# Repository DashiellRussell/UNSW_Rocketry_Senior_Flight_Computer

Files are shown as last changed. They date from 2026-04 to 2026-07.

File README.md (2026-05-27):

# UNSW Rocketry Senior Flight Computer

KiCad project for the senior flight computer used by UNSW Rocketry.

## Revisions

This repo holds each hardware revision in its own self-contained folder. Every
folder is a complete KiCad project (schematic, PCB, and its own copy of the
footprint library) so any revision can be opened and fabricated independently.

| Revision | Folder | Status |
| --- | --- | --- |
| **v0.0** | [`v0.0/`](v0.0/) | Frozen — known-good design. Do not edit. |
| **v1.0** | [`v1.0/`](v1.0/) | In progress — next revision (component + design changes). |

The exact v0.0 snapshot is also recoverable from the `v0.0` git tag
(`git checkout v0.0`).

> **Working on a new revision?** Copy the latest frozen folder to the next
> version number (e.g. `cp -R v1.0 v1.1`), then edit the copy. Tag the old one
> before you move on.

## Documents

Reference docs live in [`docs/`](docs/) and render inline on GitHub:

- [Schematic (PDF)](docs/UNSW_Rocketry_Senior_Flight_Computer.pdf) — exported full schematic (v0.0)
- [Project OZONE](docs/Project%20OZONE.pdf)

## Project layout (within each revision folder)

| File | Purpose |
| --- | --- |
| `UNSW_Rocketry_Senior_Flight_Computer.kicad_pro` | KiCad project file |
| `UNSW_Rocketry_Senior_Flight_Computer.kicad_sch` | Top-level schematic |
| `UNSW_Rocketry_Senior_Flight_Computer.kicad_pcb` | PCB layout |
| `Power.kicad_sch` | Power sheet |
| `Pyros.kicad_sch` | Pyrotechnic channels sheet |
| `Comms.kicad_sch` | Communications sheet |
| `Peripherals.kicad_sch` | Peripherals sheet |
| `Indication.kicad_sch` | Status / indication sheet |
| `UNSW_ROCKETRY_LIBRARY.pretty/` | Project-specific footprint library |
| `UNSW_Rocketry_Senior_Flight_Computer.csv` | BOM export |

## Opening the project

1. Install [KiCad 10.0](https://www.kicad.org/download/) or newer.
2. Clone this repo.
3. Open the `.kicad_pro` inside the revision folder you want, e.g.
   `v1.0/UNSW_Rocketry_Senior_Flight_Computer.kicad_pro`.

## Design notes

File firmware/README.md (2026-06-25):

# OZONE flight computer — firmware

Firmware for the Project OZONE senior flight computer (STM32L452RET6).

## Layout
```
firmware/
├── SETUP.md          CubeMX project setup (do this first)
└── ozone-fw/         CubeMX-generated project (toolchain: STM32CubeIDE)
    ├── ozone-fw.ioc
    ├── Core/ Drivers/ FATFS/ USB_DEVICE/   (CubeMX-managed)
    └── app/          portable application code (survives .ioc regen)
        ├── INTEGRATION.md  how to wire app/ into main.c
        ├── Inc/      headers
        └── Src/      sources
```

## Quick start
1. Generate the CubeMX project per **SETUP.md**.
2. Integrate the **app/** layer per **app/INTEGRATION.md**.
3. Build, flash via SWD (J4), watch the heartbeat LED.

## Modules (`app/`)
| Module | Responsibility |
|---|---|
| `spi_bus` | Shared SPI1 + CS helpers |
| `ms5611` | Barometer (x2), non-blocking conversion SM + compensation |
| `h3lis331dl`  | High-g accel — launch/landing |
| `lis3dh` | Low-g accel — apogee voter |
| `sensors` | Suite bring-up, fusion, ground-zero, altitude |
| `adc_sense` | Battery + pyro-battery voltage (ADC1) |
| `pyro` | Arm / fire / continuity, opto + N-FET |
| `indication`  | RGB (TIM1 PWM), heartbeat/error LEDs, buzzer (TIM17) |
| `logging` | CSV → MicroSD via FatFs/SDMMC |
| `telemetry` | Status over USART2 (BT module) |
| `flight` | State machine + 2-of-3 apogee voting (testable, no HW) |
| `ozone_app` | Top-level init + super-loop |

## Bring-up order (recommended)
1. Power rails (no MCU) — doc §14.1.
2. Flash + heartbeat LED.
3. `sensors_init()` WHO_AM_I: H3LIS=0x32, LIS3DH=0x33, MS5611 PROM CRC ok.
4. SD logging (`logging_init`).
5. Pyro continuity on the bench with a test resistor (doc §14.7) — **no e-match**.
6. Calibrate divider ratios + apogee thresholds.

See the top-level Project OZONE technical doc for the full design rationale.

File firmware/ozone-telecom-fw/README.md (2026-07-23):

# OZONE TELECOM hub firmware

ESP32-S3-MINI-1U firmware for the OZONE Telecom board — the comms hub
companion to UNSW Rocketry's OZONE senior flight computer (STM32L452).

## What this does

The STM32 flight computer speaks a plain-text protocol (`fcd/1`, see
`firmware/tools/gcs/PROTOCOL.md`) over a UART: `whoami` -> `FCD1 {json}`,
`TLM key=value ...`, `EVT <name> ...` (flight milestones — LAUNCH, APOGEE,
DEPLOY, PYRO, LANDED), `LOG <level> <msg>`, `get`/`set`/`do ...`. This hub's
entire job is to **relay that stream, unmodified, to/from three independent
radio links at once**, add the local GPS fix as extra telemetry, and mirror
every FC line to its own microSD as an independent flight-record backup:

```
                 ┌───────────────────────────────────────────┐
                 │            ESP32-S3-MINI-1U hub            │
STM32 FC  ──UART──▶ fc_link  ──┬─▶ ws_link   (WiFi WebSocket) │
(FCD/1)   ◀──UART──            ├─▶ ble_nus   (BLE NUS)        │
                 │             ├─▶ lora_link (E22/SX1262 SPI) │
                 │             └─▶ sd_log    (microSD backup) │
                 │                                            │
                 │  gnss_link (MAX-M10S UART, RX only) ───────┼─▶ extra TLM
                 └───────────────────────────────────────────┘
```

Commands travel the other way from any of the three radios straight back to
the FC over UART, byte-for-byte, unmodified. **This hub never originates,
rewrites, filters, or replays a command** — it is a transparent pipe. The FC
alone is the safety authority for arm/fire (see
`docs/telecom-command-protocol.md` and
`firmware/ozone-fw/app/Inc/pyro_trigger.h`): key-switch continuity, arm
state, and the `fire_mode` token/CRC/seq handshake are all enforced on the
STM32 side. If you ever feel tempted to add "just a little" smarts here
(auto-retry a fire, cache the last token, etc.) — don't; that's exactly the
kind of hub-side logic that turns a safe two-board design into an unsafe one.

## Radios

| Link | Role | Library |
|---|---|---|
| WiFi | WebSocket server, `ws://<esp-ip>:81/` — any number of GCS/laptop clients | `links2004/WebSockets` |
| BLE | Nordic UART Service (NUS) — any generic BLE-UART phone app | `h2zero/NimBLE-Arduino` |
| LoRa | E22-900M22S (SX1262) transceiver, 915 MHz AU915 | `jgromes/RadioLib` |
| GNSS | u-blox MAX-M10S, NMEA, receive-only | `mikalhart/TinyGPSPlus` |
| SD backup | microSD (J8), independent flight-record mirror, SPI | `SD` (bundled with arduino-esp32) |

**WiFi + BLE coexistence:** the ESP32-S3 has one 2.4 GHz radio shared
(time-sliced) between WiFi and BLE. At this hub's actual data rates — short
text lines a few times a second — that's a non-issue. It would only start to
matter if you tried to push a large file over WiFi (e.g. bulk log download)
at the same moment BLE traffic is heavy; for low-rate telemetry + occasional
commands, both run fine simultaneously.

**LoRa is fully independent** — separate 915 MHz radio, separate SPI bus, no
interaction with the WiFi/BLE 2.4 GHz side at all.

## Framework choice

Arduino-ESP32 via PlatformIO, not raw ESP-IDF. Reasoning: all four
libraries above are mature, actively-maintained Arduino libraries with
first-class SX126x/NimBLE/WebSocket support; reimplementing the BLE GATT
server and LoRa SPI driver from scratch in raw IDF would cost far more time
for no functional benefit on a board that isn't even fabbed yet. Everything
still runs on the same FreeRTOS/lwIP ESP-IDF underneath.

## Pin map

**Derivation method:** every pin below was reverse-engineered from the real
schematic (`ozone_telecom/ozone_telecom.kicad_sch`) by matching each net's
`global_label` coordinate against the ESP32-S3-MINI-1U symbol's pin-offset
table (symbol placed at `(81.28, 96.52)`, rotation 0°; absolute pin position
= placement + pin offset). Where that produced a clean, unambiguous match
against a single named GPIO pin, it's marked **CONFIRMED**. One net pair
could not be resolved this way and is marked **CONFIRM** — see below.

| Signal | ESP32-S3 GPIO | Status | Notes |
|---|---|---|---|
| E22 MISO | IO3 | CONFIRMED | shares ESP32 JTAG-select strap pin — fine as plain GPIO post-boot |
| E22 MOSI | IO5 | CONFIRMED | |
| E22 SCK | IO4 | CONFIRMED | |
| E22 NSS (CS) | IO6 | CONFIRMED | |
| E22 BUSY | IO7 | CONFIRMED | poll before every SPI transaction (SX1262 requirement) |
| E22 NRST | IO8 | CONFIRMED | active low |
| E22 DIO1 | IO2 | CONFIRMED | SX1262 IRQ (TX/RX done, timeout) |
| E22 RXEN | IO0 | CONFIRMED | **shares ESP32 boot-strap pin** — verify RXEN's power-on default doesn't fight the boot-mode strap; flagged for bring-up |
| E22 TXEN | IO1 | CONFIRMED | |
| GNSS TX -> ESP RX | IO39 | CONFIRMED | NMEA out from MAX-M10S |
| GNSS RX <- ESP TX | IO38 | CONFIRMED | wired through for UBX config, rarely used (module is otherwise RX-only per hardware) |
| GNSS PPS | IO37 | CONFIRMED, but see caveat below | |
| I2C SDA | IO13 | CONFIRMED | |
| I2C SCL | IO44 (native `RXD0`) | CONFIRMED | UART0 not used as a console here, repurposed as GPIO |
| RGB status LED | IO43 (native `TXD0`) | CONFIRMED | repurposed, same reasoning |
| Servo enable | IO9 | CONFIRMED | not driven by this firmware (no servo function implemented yet) |
| Servo PWM | IO20 (native `USB_D+`) | CONFIRMED | repurposed; USB isn't wired out on this board |
| Buttons BTN1/2/3 | IO12 / IO11 / IO10 | CONFIRMED | bench/debug buttons, unused by this firmware |
| VBAT_SENSE (ADC) | IO15 | CONFIRMED | unused by this firmware; hub power monitoring, add if wanted |
| FC_3V3_SENSE (ADC) | IO14 | CONFIRMED | ditto |
| CAN RX/TX (SN65HVD230, bonus) | IO21 / IO26 | CONFIRMED | not used by this firmware |
| microSD SCK/MISO/MOSI/CS (J8, flight backup) | IO36 / IO35 / IO34 / IO33 | CONFIRMED | used by `sd_log.cpp` — independent FCD backup, own SPI bus (`FSPI`) separate from the E22's `HSPI` |
| **FC UART TX** | **IO17 (placeholder)** | **CONFIRM — SEE BELOW** | |
| **FC UART RX** | **IO18 (placeholder)** | **CONFIRM — SEE BELOW** | |

### The one pin pair you must verify before flashing: the FC UART link

The `TELECOM_TO_OZONE` / `OZONE_TO_TELECOM` nets — the actual FCD-over-UART
link to the STM32 — did **not** resolve cleanly against a plain GPIO pin
using the same coordinate-matching method that nailed every other net on
this board. The coordinates land right next to the ESP32 module's `EN`
(chip-enable/reset) pin cluster instead of a clean data-GPIO pair, which is
suspicious — either (a) it really is a reset/status line rather than the UART
data pair, or (b) the net routes through a connector on
`peripherals.kicad_sch` in a way this parse didn't fully resolve.

**Action for Dash:** open `ozone_telecom.kicad_sch` in KiCad, click the
`TELECOM_TO_OZONE` and `OZONE_TO_TELECOM` labels, and use
*Inspect > Highlight Net* (or just follow the wires) to read the real ESP32
GPIO numbers, then update `PIN_FC_UART_TX` / `PIN_FC_UART_RX` in
`include/config.h`. The firmware builds and can be bench-tested with jump
wires in the meantime — the placeholders (IO17/IO18, ESP32-S3's default
UART1 pins) are only there so nothing is left undefined.

### Other discrepancy worth flagging

`docs/ozone-telecom-routing.md` says *"PPS (GNSS→IO35)"* and *"E22 SPI
(IO10–13) short and grouped"*. The schematic itself (which this pin map was
derived from, and which should be ground truth) instead has GNSS PPS on
**IO37** and the E22 SPI/control group on **IO0–IO8**, with IO35 actually
carrying the (unused-by-this-firmware) microSD MISO line. That routing doc
may simply predate the final schematic revision — flagging so Dash can
reconcile the two rather than silently trusting one.

## SD backup logging (independent flight-record mirror)

The telecom board carries its **own** microSD (J8, Molex 47219-2001, SPI
mode — `Connector:Micro_SD_Card` in `ozone_telecom/peripherals.kicad_sch`),
separate from the flight computer's SD card that logs `OZONE000.CSV` etc.
(`firmware/ozone-fw/app/Src/logging.c`). `src/sd_log.{h,cpp}` mirrors every
line this hub receives from the FC over UART — `TLM`, `EVT`, `LOG`,
`PARAM`, `ACK`, `FCD1` — onto that second card, so if the FC's own card is
ever lost, damaged, or unreadable after recovery, there is still a complete,
independently-wired, independently-powered copy of the flight.

**Pins** (`config.h`, CONFIRMED against the schematic — see the pin-map
table above):

| Signal | ESP32-S3 GPIO |
|---|---|
| SD_SCK  | IO36 |
| SD_MISO | IO35 |
| SD_MOSI | IO34 |
| SD_CS | IO33 |

No card-detect line is routed to the ESP for J8 — `sd_log_init()` treats a
failed `SD.begin()` as "no card" and just disables the backup for that
boot, the same way the FC's own `logging.c` had to stop trusting its
unreliable PC3 card-detect switch and started using the mount attempt
itself as the presence test.

**File naming:** `TCM000.LOG` .. `TCM999.LOG`, one new file per power-up —
deliberately mirrors the FC's `OZONE000.CSV` .. `OZONE999.CSV` scheme so the
two cards' files are recognisable as siblings of the same flight. Each line
is written as `[<hub millis()>] <verbatim FCD line>`.

**Non-blocking design:** `sd_log_line()` (called once per FC line, right
alongside the WiFi/BLE/LoRa fan-out in `main.cpp`) only appends to a small
RAM buffer — it never touches the SPI bus and is a true no-op if no card is
mounted, so it can never be the thing that stalls the radio relay. The
buffer is flushed to the card in one write+fsync every
`SD_LOG_FLUSH_PERIOD_MS` (500 ms) or sooner if it nearly fills, via
`sd_log_poll()` in the main loop — and immediately after any `EVT` line
(LAUNCH/APOGEE/DEPLOY/PYRO/LANDED), via an explicit `sd_log_flush()` call,
so the rare, safety-relevant lines aren't left sitting in RAM. The SD card
uses its own dedicated SPI bus (`FSPI`) so it can never contend with or
block the E22 LoRa radio's separate `HSPI` bus.

**This is a best-effort backup, not a required subsystem** — a missing,
full, or dead SD card on the telecom board must never affect the WiFi/BLE/
LoRa relay. If `sd_log_init()` fails at boot, or a write fails mid-flight,
the module disables itself for the rest of that boot and logs a warning to
the USB debug console; everything else keeps running exactly as before.

## Build & flash

Requires [PlatformIO](https://platformio.org/) (CLI or the VS Code
extension).

```sh
cd firmware/ozone-telecom-fw
pio run                 # build
pio run -t upload       # flash over USB (board must be in bootloader mode
                         # if it doesn't auto-reset — hold BOOT, tap RESET)
pio device monitor      # USB serial debug console (separate from the FCD
                         # links — this is Serial/USB-CDC, not the FC UART)
```

Before flashing real hardware: set `WIFI_SSID` / `WIFI_PASSWORD` (or flip
`WIFI_AP_MODE` to 1 to have the hub host its own AP instead) and confirm the
FC UART pins in `include/config.h` as described above.

## Connecting a client over each link

**WiFi (WebSocket):** connect to `ws://<esp-ip>:81/` (find the IP via
`pio device monitor` on boot, or check your router, or use the AP's fixed
gateway IP `192.168.4.1` if `WIFI_AP_MODE=1`). Any WebSocket client works —
`wscat -c ws://<ip>:81/`, a browser `new WebSocket(...)`, or the project's
own `firmware/tools/gcs` console if it's given a WS transport. Send a
newline-free text frame containing e.g. `whoami` or `do arm`; receive one
frame per FCD line (`TLM ...`, `LOG ...`, `FCD1 ...`, etc.).

**BLE (Nordic UART Service):** scan for a device named `OZONE-TELECOM`.
Connect with any generic "BLE UART" app (nRF Connect, Serial Bluetooth
Terminal, LightBlue). Subscribe to the TX characteristic
(`6E400003-...CCA9E`) for notifications (the outbound FCD stream); write to
the RX characteristic (`6E400002-...CCA9E`) to send commands. Standard NUS
UUIDs — no custom app needed.

**LoRa:** this is the actual flight radio link, matching the ground
station's own E22-900M22S module (transparent-UART LoRa point-to-point per
`docs/telecom-command-protocol.md`) at 915 MHz / SF9 / BW125 / CR 4:5 / sync
word `0x12`. Point a matching SX1262/E22 ground-station radio at the same
parameters (`firmware/tools/gcs` + a ground E22 module) and it should see
the same FCD lines the WiFi/BLE clients get, one LoRa packet per line.

## Known limitations / TODO for whoever picks this up next

- `whoami`'s `FCD1 {...}` descriptor line, if long, costs meaningful LoRa air
  time per re-send; consider caching it hub-side and only relaying the first
  reply per session if that becomes a problem in practice (would need FC
  buy-in since the FC currently owns that reply, not this hub).
- No local filtering/backpressure if a WebSocket or BLE client is slow to
  drain — `broadcastTXT`/`notify()` calls are fire-and-forget; fine for a
  low-rate text stream, but worth watching if `tlm_hz` gets pushed high.
- VBAT_SENSE / FC_3V3_SENSE ADC pins are wired and documented but not read by
  this firmware yet (not in the task's required scope — the FC already
  reports its own `vbat` in its `TLM` line).
- Buttons/servo/CAN pins are all wired on the board but intentionally
  untouched by this firmware — out of scope for the comms-hub relay job.
  (microSD is now used — see "SD backup logging" above.)
- SD backup logging has not been bench-tested on real hardware (board isn't
  fabbed yet) — the SPI pin assignment is CONFIRMED against the schematic
  using the same coordinate-matching method as every other net on this
  board, but first bring-up should still sanity-check the FSPI bus
  (SCK/MISO/MOSI/CS on IO36/35/34/33) with a real card before trusting it
  in flight.

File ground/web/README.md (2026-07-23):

# OZONE Ground Station (web)

A Next.js ground station for any `fcd/1` flight computer — a modern,
mission-control-styled replacement for the vanilla-JS dashboard in
`firmware/tools/web-dashboard/`. It **speaks plain FCD**
(`docs/fcd-protocol.md`), so it works unmodified against:

- the STM32 board directly, over USB-CDC / a UART adapter — **Web Serial**, or
- the ESP32 telecom hub over WiFi — **WebSocket**, or
- its own built-in **simulator**, with no hardware at all.

Nothing here is OZONE-specific. On connect it sends `whoami`, parses the
`FCD1 {json}` descriptor the board replies with, and builds the entire UI —
one graph per `graphs[]`, one bar per `rails[]`, one row per `checks[]`, one
control per `actions[]`, one field per `params[]` — from that JSON.

## Stack

- **Next.js 16.2** (App Router, Turbopack), static export (`output: "export"`)
  — this is a pure client app (Web Serial / WebSocket / an in-memory
  simulator are all browser APIs), so there's no server component doing
  anything interesting; everything that touches a live link is `'use client'`.
- **React 19**, **TypeScript 5.9** (strict).
- **Tailwind CSS v4** (CSS-first config via `@theme` in `app/globals.css`,
  no `tailwind.config.js` needed).
- **pnpm**.
- Fonts: `Aldrich` (display/headings) + `JetBrains Mono` (everything else —
  labels, data, log), loaded via `next/font/google`.
- **Glassmorphism chrome**: every panel is a frosted `.glass`/`.surface` card
  (real `backdrop-filter: blur()+saturate()`) floating over a full-bleed
  `<canvas>` (`components/Backdrop.tsx`) painting slow-drifting, very-low-
  alpha cyan/amber blobs — same recipe as Spiral Blue's Risley console,
  reskinned onto OZONE's own cyan/amber/red/green palette. Nested content
  (graph cards, rail rows, log pane, param rows, prompt code block) uses
  `.frost` instead of `.glass`, since a `backdrop-filter` silently no-ops
  nested inside an already-blurred ancestor — see the comment block above
  `.glass`/`.frost` in `app/globals.css`.
- Charts: a small dependency-free canvas renderer (`lib/chart.ts`, ported
  from the vanilla dashboard's `chart.js`) rather than a charting library —
  full control over the look, and graph updates never touch React state (see
  **Architecture** below), so they stay smooth at telemetry rate.

## Run it

```bash
cd ground/web
pnpm install
pnpm dev        # http://localhost:3000
```

Other scripts:

```bash
pnpm build      # production build + static export to out/
pnpm start      # serve the .next build (non-static mode) — for local testing
pnpm typecheck  # tsc --noEmit
```

No hardware on you? Just hit **Connect** with **Built-in simulator**
selected (the default) — it runs a small deterministic flight model (boost →
coast → apogee → descent → landed) through the exact same FCD parsing path
as a real board, so every panel (checks, rails, graphs, log, and all four
pyro fire modes) can be demoed cold. A **SIMULATED** badge appears in the
connect bar whenever it's driving the UI.

## Deploying

Static output (`next.config.ts` sets `output: "export"`), so it's a plain
static site — deploy the `out/` directory anywhere, or just point Vercel at
this directory (`ground/web`) with the default Next.js build command; no
environment variables or backend services are required. Web Serial requires
a secure context (`https://` or `http://localhost`), which Vercel's preview/
prod URLs satisfy automatically.

## Connecting

**Auto-detect (Web Serial only).** On load, the console silently checks
`navigator.serial.getPorts()` for a port this origin was already granted
access to (from a previous manual "Connect board" click) — preferring one
that matches OZONE's USB-CDC identity (VID `0x0483` / PID `0x5740`, an
STM32 "Virtual ComPort"), else any granted port. If found, it reopens it
with **no click and no picker** and runs the FCD handshake straight away.
It also listens for `navigator.serial`'s `connect`/`disconnect` hotplug
events, so plugging the board in later (once a port has been granted once)
auto-connects, and unplugging it tears the link down cleanly and falls back
to the simulator instead of just going dead. Browsers block the native port
picker without a user gesture, so **the very first-ever authorization is
always one manual click** — after that, auto-detect takes over.

If no authorized port is found (or Web Serial isn't supported in this
browser at all), the console falls back to the **built-in simulator**
automatically — you land on a live, fully-populated dashboard immediately,
no hardware required, with a `simulated` badge in the top nav.

The connection cluster lives in the top nav (top-right): a status pill
(green dot = a real board, cyan = simulator, amber/pulsing = searching,
grey = disconnected) doubles as a popover trigger — click it to pick a
different transport:

- **USB** (Web Serial) — a "Connect board" quick-button also appears
  whenever the console isn't already on a real board; both it and the
  popover's Connect button call `requestPort()` pre-filtered to OZONE's
  VID/PID, so the native picker only lists the board (or nothing, if it's
  not plugged in). Chrome/Edge only — the option is disabled elsewhere
  (WebSocket + simulator still work everywhere).
- **WiFi** (WebSocket, ESP32 telecom hub) — enter the hub's URL, e.g.
  `ws://192.168.4.1:81`. The hub is expected to bridge the WebSocket 1:1 to
  the board's UART, forwarding the exact same `fcd/1` text lines both ways.
- **Sim** (built-in simulator) — no fields needed, just Connect.

On any connect, the console sends `whoami` and waits up to 1.5&nbsp;s for a
line starting `FCD1 `. If nothing arrives (a non-conforming or not-yet-
flashed board), it falls back to a generic empty profile — you still get raw
`TLM`/`LOG` line parsing, just no checks/rails/graphs/params/actions until
firmware declares them. A banner on the dashboard flags that fallback state.

If the board re-announces itself later (reboot, mode change) — any `FCD1 `
line seen mid-session rebuilds the whole UI again, same as the initial
handshake.

## Routes

Both routes share one sticky top nav (`components/TopNav.tsx`, mounted once
in `app/layout.tsx`) — brand + Console/Protocol pills on the left, the
connection cluster on the right — so it's identical wherever you are.

- `/` — the ground station (waiting screen → live dashboard).
- `/protocol` — a spec hub: the full `fcd/1` protocol doc rendered from
  markdown, plus a copy-pastable "implement FCD on your board" prompt
  (ESP32/STM32 toggle). Reachable via the **Protocol** pill in the top nav;
  the **Console** pill goes back.

## File layout

```
ground/web/
├── app/
│   ├── layout.tsx        fonts, metadata, backdrop/noise overlays, mounts
│   │                     FcdConnectionProvider + TopNav once for every route
│   ├── page.tsx          console: waiting screen / live dashboard
│   ├── protocol/page.tsx  spec hub: Server Component, reads content/*.md at build time
│   └── globals.css       Tailwind v4 @theme tokens + the mission-control chrome
├── content/               markdown vendored 1:1 from ../../docs/ (source of truth lives there;
│   ├── fcd-protocol.md            re-copy here if the source docs change)
│   └── fcd-implementer-prompts.md
├── hooks/
│   ├── FcdConnectionProvider.tsx  lifts one useFcdConnection() instance above both
│   │                              TopNav (in the layout) and the page content, so they
│   │                              share a single live transport instead of racing
│   └── useFcdConnection.ts   app glue: connect flow, handshake, line routing,
│                              command dispatch + reply correlation (ported
│                              from js/main.js's App class)
├── lib/                  framework-agnostic protocol/transport modules
│   ├── types.ts           Descriptor/Profile/Check/Rail/Graph/Param/Action types
│   ├── fcd.ts              FCD1/TLM/LOG/PARAM/ACK parsing + do/set command framing (ported js/fcd.js)
│   ├── transports.ts       SerialTransport (Web Serial, incl. OZONE VID/PID filters,
│   │                       getAuthorizedPorts()/connectPort() for auto-detect, and the
│   │                       onHotplug() connect/disconnect wiring) + WebSocketTransport
│   ├── sim.ts              SimTransport — mock FCD/1 board + flight model (ported js/sim.js)
│   ├── chart.ts            canvas scrolling line chart (ported js/chart.js)
│   ├── bus.ts               tiny per-id pub/sub so graph samples repaint canvases
│   │                        directly without cycling through React state
│   ├── accent.ts           descriptor accent name -> colour
│   └── docs.ts              server-only fs readers for content/*.md — also parses
│                            the two ```text prompt fences out of the implementer-
│                            prompts doc (single source of truth, no hand-retyping)
└── components/
    ├── Backdrop.tsx                        (drifting-blob canvas, mounted once in app/layout.tsx)
    ├── TopNav.tsx                           (shared glass top nav — brand, Console/Protocol
    │                                        pills, connection cluster — mounted once in
    │                                        app/layout.tsx, replaces the old ConnectBar.tsx)
    ├── WaitingScreen.tsx, BoardHeader.tsx
    ├── ChecksPanel.tsx, RailsPanel.tsx
    ├── GraphsPanel.tsx, GraphCard.tsx
    ├── LogPanel.tsx
    ├── ParamsPanel.tsx
    ├── ActionsPanel.tsx, ActionModal.tsx  (args + confirm-token modal)
    ├── PyroPanel.tsx                       (the 4 fire_mode operator flows)
    ├── ConfirmModal.tsx
    ├── Toast.tsx                           (reply toasts, context-provided)
    ├── MarkdownDoc.tsx                     (styled react-markdown renderer, /protocol)
    └── PromptSwitcher.tsx                  (ESP32/STM32 toggle + copy-to-clipboard, /protocol)
```

## Architecture notes

- **Self-describing UI.** `lib/types.ts#normaliseProfile` is the only place
  that understands the descriptor shape; every panel component just maps
  over `profile.checks/rails/graphs/params/actions` — add a field in
  firmware, declare it, it renders here with zero client changes.
- **Graphs bypass React state.** `useFcdConnection` publishes each TLM
  sample's graph values onto a `GraphBus` (`lib/bus.ts`); `GraphCard` pushes
  straight into its own `ScrollChart` canvas instance. This keeps live
  telemetry at 10 Hz+ from re-rendering the whole tree — the canvas owns its
  own paint loop, same design as the vanilla dashboard's `chart.js`.
- **Rails/checks/log/pyro** are lower-rate and do live in React state
  (`useFcdConnection`), since re-rendering a handful of small components at a
  few Hz is cheap and keeps that logic simple/testable.
- **The board is always the safety authority.** Every pyro/arm/fire control
  here is an operator-side guard on top (typed confirmation, danger styling,
  hold-to-fire) — it never assumes a command will succeed and always
  surfaces the board's actual `ACK`/`ERR` reply via a toast.

## The pyro fire handshake (all four `fire_mode`s)

Driven by `firmware/ozone-fw/app/Inc/pyro_trigger.h` /
`docs/fcd-protocol.md` §7. `PyroPanel.tsx` reads the active mode from the
`fire_mode` enum param (if the board declares one) and renders the matching
flow per channel:

| mode | flow |
|---|---|
| `safe` | **Prime** → board issues a fresh one-shot token + a countdown window → typed **FIRE** confirmation sends that token back. Two round-trips per fire; for planned ground tests. |
| `session` | **Enter flight mode** (`do flight_mode [key=]`) sets a flight-long key once (ground-supplied or board-rolled) → every subsequent fire is a single typed-**FIRE** click using that key. |
| `hot` | **Deploy-ready** latches per channel → the board's live rolling token (streamed as `dtok<N>` in telemetry, rotates ~4s) ticks live → a single guarded **FIRE** click auto-fills the current token. Recommended for in-flight emergency manual deploy. |
| `direct` | No token — a **hold-to-fire** button (~1.4s) is the only operator-side guard, since the board's own interlock is just armed + continuity + key switch. |

Arm/disarm has its own typed **ARM** confirmation and a pulsing red **ARMED**
pill; per-channel continuity (`cont1..contN`, N = `caps.pyro`) gates whether
any fire control is even clickable.

## Command integrity (CRC + seq)

Per `docs/fcd-protocol.md` §8, safety commands can carry a trailing
`seq=<n>*<CRC>`. This client turns it on automatically when the descriptor
sets `caps.integrity: true`, framing exactly:

```
arm, disarm, flight_mode, prime, deploy_ready, fire
```

(`safe` is deliberately **not** integrity-framed — it only clears
prime/deploy-ready/session state, nothing fires.) `seq` is a per-session
monotonic counter kept client-side (`lib/fcd.ts`'s caller in
`hooks/useFcdConnection.ts`); the CRC is an XOR of every byte in the line up
to (not including) the `*`, hex-encoded — matches the firmware's `fcd.c`
computation (`lib/fcd.ts#xor8`).

```
do fire ch=1 token=8341 seq=7*4A
```

## Reconciliations applied in this port (vs. the vanilla dashboard)

The vanilla `firmware/tools/web-dashboard` guessed a couple of wire-level
details that the task brief has since pinned down; this client implements
the corrected versions:

1. **Session-mode command.** The vanilla client invented `do session_key
   [key=]`. The real command is **`do flight_mode [key=HHHH]`** — the same
   action used to enter flight mode generally, which in `session` fire_mode
   *also* establishes/returns the flight pyro key on the same `ACK` line
   (`ACK flight_mode key=51992`). See `lib/sim.ts`'s `flight_mode` handler and
   `PyroPanel.tsx`'s session row.
2. **CRC algorithm.** Confirmed as XOR-fold-8 over the bytes before `*`,
   hex-encoded uppercase — `lib/fcd.ts#xor8` (unchanged from the vanilla
   client's implementation, which already guessed correctly).
3. **Which actions get CRC+seq framing.** Reconciled to exactly `arm`,
   `disarm`, `flight_mode`, `prime`, `deploy_ready`, `fire` (`safe` dropped
   from the vanilla client's broader guess, since it never fires or arms).

## FCD ambiguities still open (unchanged from docs/fcd-protocol.md §11)

These are protocol-level, not client-level — flagged here so firmware
doesn't silently diverge from what this client assumes:

1. **`checks[]` have no defined live wire representation.** There's no
   `CHECK` line type in FCD/1 — only `TLM`/`LOG`/`ACK`/`ERR`/`PARAM`. This
   client infers each check's pass/fail/warn from telemetry: an exact
   boolean TLM key match on the check `id` (best case), otherwise heuristics
   for well-known ids (`power`/`vbat` from the `vbat` rail's min/max, `pyro`
   from `cont1..N`, `baro` from `pressure_pa` presence). Anything else sits
   at "monitoring…" until the board gives it a signal — cleanest fix is a TLM
   key matching the check id (e.g. `sd=1`), which needs no client changes.
2. **`caps.integrity` isn't in `docs/fcd-protocol.md`'s current schema.**
   This client reads an assumed `caps.integrity: true/false` (default off).
   Add that key to OZONE's real descriptor once `fcd.c` exists, or specify a
   different signal for this client to key off.
3. **`get` reply framing** (one `PARAM` line per param vs. one packed line)
   is left as an implementation choice by the protocol doc; this client
   doesn't currently call bare `get` (it reads params from the `FCD1`
   descriptor's `value` fields and only ever `set`s), so it's unaffected
   either way, but a future params-refresh button would need to pick one.

None of these affect the descriptor-driven rendering (graphs/rails/params/
actions) — only the pyro trigger's command framing and the preflight-check
inference.

## Browser support

- **Chromium (Chrome/Edge/Brave/Opera):** full support, including Web Serial.
- **Firefox/Safari:** WebSocket + simulator transports work; Web Serial is
  disabled in the transport dropdown (not implemented by those browsers as
  of this writing).
- Web Serial requires a secure context — `http://localhost` is fine for
  local dev, anything else needs `https://`.

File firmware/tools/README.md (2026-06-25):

# OZONE ground tools

Laptop-side companion to the on-board USB-C console.

## ozone_console.py
A `rich` TUI that drives the firmware's Preflight / Test / Post-flight menus over
the USB-C virtual COM port.

### Run with pnpm (from `firmware/`, matches the MPR workflow)
```bash
pnpm setup        # one time: pip installs rich + pyserial
pnpm preflight    # run preflight checks (table)
pnpm monitor      # live telemetry dashboard
pnpm postflight   # flight summary + SD log list
pnpm console      # full interactive menu
pnpm terminal     # raw passthrough
pnpm ports        # list serial ports
```

### Or run Python directly
```bash
pip install -r requirements.txt          # rich + pyserial
python ozone_console.py                  # auto-detects the OZONE port
python ozone_console.py --mode preflight # jump straight to a view
python ozone_console.py --list           # list serial ports
python ozone_console.py --port /dev/cu.usbmodem1234
```

Menu:
- **1) Preflight** — runs the board's preflight checks, renders a colored
  pass/fail table + overall result.
- **2) Live monitor** — toggles status streaming and shows a live dashboard
  (altitude/AGL, velocity, pressure/temp, accel, battery bar, arm + continuity).
  Ctrl-C stops and turns streaming back off.
- **3) Post-flight** — flight summary (apogee, deploy events) + SD log listing,
  with an optional make-safe (disarm).
- **4) Raw terminal** — straight passthrough to the board console (type the menu
  numbers yourself).

### How it works
The board firmware (`app/Src/console.c`) is the source of truth — it presents
text menus and emits fixed-format status/preflight lines. This tool just sends
the menu keystrokes and parses those lines. You can always talk to the board
with any plain serial terminal (screen/minicom/PuTTY) instead; the TUI is just a
nicer front-end.

> Note: USB CDC ignores baud rate, but set 115200 8N1 in plain terminals anyway.
> macOS port is usually `/dev/cu.usbmodemXXXX`; Linux `/dev/ttyACM0`.

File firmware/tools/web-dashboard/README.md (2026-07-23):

# OZONE Web Ground Station

A browser-based ground station for any `fcd/1` flight computer — a more
aesthetic, mission-control-styled alternative to the `gcs` terminal TUI
(`firmware/tools/gcs/`). Same rule as the TUI: **it speaks plain FCD**
(`firmware/tools/gcs/PROTOCOL.md`), so it works unmodified against:

- the STM32 board directly, over USB-CDC / a UART adapter (Web Serial), or
- the ESP32 telecom hub over WiFi (WebSocket), or
- its own built-in simulator, with no hardware at all.

Nothing here is OZONE-specific. On connect it sends `whoami`, parses the
`FCD1 {json}` descriptor the board replies with, and builds the entire UI —
one graph per `graphs[]`, one bar per `rails[]`, one row per `checks[]`, one
control per `actions[]`, one field per `params[]` — from that JSON. Add a
sensor in firmware, declare it, and it shows up here with zero changes to
this code.

## Run it

No build step, no `npm install`. It's plain ES modules + a hand-rolled canvas
chart — just serve the folder and open it:

```bash
cd firmware/tools/web-dashboard
python3 -m http.server 8787
# then open http://localhost:8787
```

(A real HTTP server is required, not `file://` — ES modules and the Web
Serial API are both blocked on `file://` by browser security policy. Any
static server works: `npx serve`, `caddy file-server`, VS Code "Live Server", etc.)

Open it in **Chrome or Edge** for the Web Serial transport (Firefox/Safari
don't implement it yet — the WebSocket and simulator transports still work
everywhere).

No hardware on you? Pick **Built-in simulator** in the connect bar top-left —
it runs a small deterministic flight model (boost → coast → apogee → descent
→ landed) through the exact same FCD parsing path as a real board, so the
whole UI (graphs, rails, checks, log, and all four pyro fire modes) can be
demoed cold.

## Connecting

The connect bar (top of the page) has one dropdown for transport + a Connect
button:

- **Web Serial (USB / UART)** — click Connect, the browser's native port
  picker opens, choose the STM32's USB-CDC port (or a UART/BT-serial adapter
  wired to USART2). Set the baud rate first if it's not 115200.
- **WebSocket (ESP32 telecom hub)** — enter the hub's WebSocket URL, e.g.
  `ws://192.168.4.1:81`, and Connect. The hub is expected to bridge the
  WebSocket 1:1 to the board's UART, forwarding the exact same `fcd/1` text
  lines both ways — no framing translation needed on either side.
- **Built-in simulator** — no fields needed, just Connect.

On connect, the console sends `whoami` and waits up to 1.5&nbsp;s for a line
starting `FCD1 `. If nothing arrives (a non-conforming or not-yet-flashed
board), it falls back to an empty generic profile — you still get raw
`TLM`/`LOG` line parsing, just no checks/rails/graphs/params/actions until the
firmware declares them. A banner in the dashboard tells you when you're in
that fallback state.

If the board re-announces itself later (reboot, mode change) — any `FCD1 `
line seen mid-session rebuilds the whole UI again, same as the initial
handshake.

## Layout

```
web-dashboard/
├── index.html          shell: connect bar, waiting screen, dashboard containers
├── css/style.css        dark mission-control theme (all in one file, no build step)
├── js/
│   ├── fcd.js           protocol layer: parse FCD1/TLM/LOG/PARAM/ACK lines,
│   │                    build `do`/`set` command strings incl. CRC+seq framing
│   ├── transports.js    SerialTransport (Web Serial) + WebSocketTransport,
│   │                    both behind one connect/send/onLine/onClose interface
│   ├── sim.js            SimTransport — a mock FCD/1 board implementing the
│   │                    same interface, so main.js can't tell it apart from
│   │                    a real link. Runs a small flight model + the full
│   │                    pyro_trigger.h handshake for all 4 fire_modes.
│   ├── chart.js          dependency-free canvas scrolling line chart
│   ├── ui.js             descriptor -> DOM: checks/rails/graphs/params/actions
│   │                    panels, the confirm-token modal, the log pane
│   ├── pyro.js           the pyro control panel: arm/disarm + the 4 fire-mode
│   │                    operator flows (safe/session/hot/direct)
│   └── main.js           glue: connect flow, handshake, line routing,
│                         command dispatch + reply correlation
└── README.md
```

No external CDN calls, no vendored charting library — the scrolling graphs
are a ~120-line canvas renderer (`js/chart.js`) rather than a bundled
Chart.js/D3, so there's genuinely nothing to fetch or build.

## Feature parity with the `gcs` TUI

- **Self-describing UI** from the `FCD1` descriptor (checks/rails/graphs/tlm/
  states/params/actions/caps) — same schema, same `from_manifest`-equivalent
  path as `model.py`.
- **Preflight checks** — pass/fail/warn rows per `checks[]`.
- **Live graphs** — one scrolling chart per `graphs[]`, auto-scaled, with a
  live readout.
- **Voltage rail bars** — coloured green/yellow/red by `[min,max]` + edge band,
  per `rails[]`.
- **Event log pane** — colour-coded by `LOG <level>`, with running err/warn
  counters, auto-scrolling, capped history.
- **Arm/disarm** with typed `ARM` confirmation and a pulsing red ARMED pill.
- **Per-channel continuity** — `cont1..contN` (N = `caps.pyro`) shown as a
  CONT/OPEN badge per channel, gating whether fire controls are even usable.
- **The pyro fire handshake, all four `fire_mode`s** (see below) — with
  typed `FIRE`/`ARM` confirmation modals and red danger styling throughout,
  same "operator-side guard on top, board is still the source of truth" model
  as the TUI's two-press confirm.
- **Descriptor-driven params/actions panels** — editable fields per `params[]`
  (float/int/bool/enum), buttons per `actions[]` with prompted args, confirm
  tokens, and danger styling — same generic rendering as `screens.py`'s
  `run_control`.

## The pyro fire handshake (all four modes)

Driven by `pyro_trigger.h` / `docs/telecom-command-protocol.md`. The pyro
panel reads which mode is active from a `fire_mode` enum param (if the board
declares one) and renders the matching flow per channel. **The external key
switch + board-side interlocks are always authoritative** — this UI only adds
an operator-side guard on top (typed confirm, danger styling, hold-to-fire);
it never assumes a fire will succeed and always surfaces the board's actual
`ACK`/`ERR` reply.

| mode | flow |
|---|---|
| `safe` | **Prime** button → board issues a fresh one-shot token + a countdown window → typed **FIRE** confirmation sends that token back. Matches "planned ground tests" in the docs. |
| `session` | One flight-wide key is set once (`session_key`, ground-supplied or board-rolled) → every subsequent fire is a single typed-**FIRE** click using that key, no per-fire prime step. |
| `hot` | **Deploy-ready** latches per channel → the board's live rolling token (streamed as `dtok<N>` in telemetry) is shown ticking → a single guarded **FIRE** click auto-fills the current token. This is the "pay the safety cost before the emergency" mode from the docs. |
| `direct` | No token at all — a **hold-to-fire** button (~1.4 s) is the only operator-side guard, since the board's own interlock is just armed + continuity + key switch. |

## Command integrity (CRC + seq)

Per `docs/telecom-command-protocol.md`, safety commands can carry a trailing
`seq=<n>*<CRC>`. The dashboard turns this on automatically when the
descriptor sets `caps.integrity: true`, framing `arm`/`disarm`/`prime`/`fire`/
`deploy_ready`/`session_key`/`safe` (see **ambiguities** below) as e.g.:

```
do fire ch=1 token=8341 seq=7*4A
```

`seq` is a per-session monotonic counter kept client-side; the CRC covers the
whole line up to the `*`, hex-encoded.

## FCD ambiguities resolved (please sanity-check against real firmware)

`PROTOCOL.md` and the telecom doc leave a few wire-level details unspecified.
This client makes a reasonable choice for each and documents it here so
firmware doesn't silently diverge:

1. **Checks[] have no defined live wire representation.** There's no `CHECK`
   line type in FCD/1 — only `TLM`/`LOG`/`ACK`/`ERR`/`PARAM`. The dashboard
   infers each check's pass/fail/warn from whatever telemetry already tells
   it: a boolean TLM key exactly matching the check `id` (best case, if the
   board streams one), otherwise heuristics for the well-known ids (`power`
   from the `vbat` rail's min/max, `pyro` from `cont1..N`, `baro` from
   `pressure_pa` presence). Anything else just sits at "monitoring…" until
   the board gives it a signal. **If you want deterministic preflight
   checks, the cleanest fix is to add TLM keys matching the check ids**
   (e.g. `sd=1`), which the dashboard will pick up with no code changes.
2. **`SESSION` mode's ground command isn't named in the docs.** The doc's
   worked examples only cover `safe`/`hot`/`direct`; `pyro_trigger.h` has a
   `pyro_trigger_arm_session()` entry point but no `do <id>` binding is
   specified. This client calls it `session_key` (optional `key=` arg, blank
   = let the board roll one) — see `SIM_FCD`/`sim.js` and `pyro.js`. If
   firmware lands on a different action id, only that one string needs to
   change on this side.
3. **Which actions get CRC+seq framing.** The doc names `arm`/`deploy_ready`/
   `prime`/`fire` explicitly; this client also frames `disarm`/`safe`/
   `session_key` since they mutate the same trigger state machine and a
   glitched `disarm`/`safe` is just as unsafe to misread as a glitched `arm`.
   Toggle the `SAFETY_ACTIONS` set in `js/main.js` if that's wrong.
4. **`caps.integrity` isn't in the current `PROTOCOL.md` schema.** The
   protocol doc lists `caps.pyro`/`arm`/`logs`/`telemetry` but nothing that
   signals whether a board expects CRC+seq framing. This client reads an
   assumed `caps.integrity: true/false` (defaults off) — add that key to
   OZONE's real descriptor once `fcd.c` exists, or tell this client a
   different signal to look for.
5. **CRC algorithm.** The telecom doc says "CRC (XOR/CRC8 of the line up to
   `*`), hex" without pinning the exact polynomial/variant. `js/fcd.js`
   implements a straight XOR-fold-8 (cheapest possible on an 8-bit path) —
   swap `xor8()` for whatever `pyro_trigger`'s firmware side actually computes
   before relying on this for real safety commands.

None of these affect the descriptor-driven rendering (graphs/rails/params/
actions) — only the pyro trigger's command framing and the preflight-check
inference, both called out above and both easy to retarget in one place each
(`js/pyro.js` action ids, `js/main.js` `SAFETY_ACTIONS`, `js/fcd.js` `xor8`).

## Browser support

- **Chromium (Chrome/Edge/Brave/Opera)**: full support, including Web Serial.
- **Firefox/Safari**: WebSocket + simulator transports work; Web Serial is
  greyed out in the transport dropdown (not implemented by those browsers as
  of this writing).
- Requires a secure context for Web Serial (`http://localhost` is fine for
  local dev; anything else needs `https://`).

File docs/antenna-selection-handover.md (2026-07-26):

# OZONE Telecom — Antenna Selection Handover

Purpose: brief a fresh agent to help pick antennas + RF jumpers for the OZONE Telecom board. Everything needed is here; no prior context required. Board is UNSW Rocketry's AURC telemetry board (companion to the OZONE senior flight computer).

## 1. What the board is / the RF architecture

Three radios, three separate antenna chains, all exiting on **board-edge SMA connectors**:

| Radio | Chip/module | Band | TX or RX | Antenna port on board |
|---|---|---|---|---|
| LoRa telemetry (the flight link) | Ebyte **E22-900M22S** (Semtech SX1262) | **915 MHz** (AU ISM 902–928) | **Transceiver** (TX up to 22 dBm + RX) | edge SMA |
| BLE / Wi-Fi | **ESP32-S3-MINI-1U** | **2.4 GHz** | Transceiver | edge SMA |
| GNSS | u-blox **MAX-M10S** | **GPS L1, 1575 MHz** | **Receive only** | edge SMA |

**Connector details (important for ordering):**
- All three board SMAs are **standard SMA, female jack** (Amphenol 132289 edge-mount). → **Antennas must be standard SMA *male*.** **NOT RP-SMA** (RP-SMA is the Wi-Fi-consumer variant and will not mate — a real trap for cheap 2.4 GHz antennas).
- LoRa & ESP: the module has its own **U.FL** connector → a short **U.FL-to-U.FL jumper** goes to an **onboard relay U.FL** → short 50 Ω trace → the edge SMA. **Fallback:** unplug the jumper and run the module U.FL straight to an antenna via a U.FL-to-SMA pigtail (bypasses the board trace). So the SMAs are mainly for the **ground station and bench**; on the rocket the antenna can also hang directly off the module U.FL.
- GPS: MAX-M10S RF_IN → DC-block cap → 50 Ω trace → edge SMA, **with an active-antenna bias-T populated** (VCC_RF → 27 nH onto the RF line). So **the GPS port can drive an ACTIVE antenna** (~3.3 V bias).

**Critical rule — active vs passive:**
- **GPS is receive-only → can use an ACTIVE antenna** (built-in LNA, powered up the coax). This is the *only* port with bias.
- **E22 (LoRa) and ESP are transceivers → PASSIVE antennas only.** They transmit real power out the port; an active antenna's receive-LNA would be destroyed. Never feed DC to these ports.

## 2. Use cases — two very different ends

**Rocket end (the moving/harsh end):**
- Under **high-G acceleration + vibration**, and it **tumbles** (orientation changes, especially on descent).
- Airframe is **fibreglass/plastic (RF-transparent)** where antennas mount — so **no metal ground plane available**, and antennas mount **internally, along the airframe axis, epoxied/secured**.
- Requirements: **rigid** (NO flexible "duck" whips, NO tilt/swivel bases — mechanical failure points under G), **omnidirectional** (a tumbling rocket must not lose the link when it points away → low/modest gain, wide pattern), **low height / length-constrained** (fits an avionics bay / RF-transparent section), and ideally **ground-plane-independent** (half-wave or dipole) since there's no ground plane.

**Ground station end (the fixed/easy end):**
- Not under G, mounts on a tripod/mast. Can be tall, high-gain, directional.
- **High gain (Yagi, aimed)** for maximum range, **or** a simple **omni (no aiming)** for a conservative link.
- **Elevation + clear line-of-sight matters more than antenna gain** for a no-aim setup.

## 3. Antenna-selection principles being used
- **Gain (dBi) = directional concentration vs an isotropic radiator**, not amplification (antennas are passive). High gain = narrow beam = more range one way, less coverage elsewhere. **Negative dBi = inefficient** (radiates less than isotropic — a red flag on small antennas).
- Therefore: **omni + modest gain on the tumbling rocket; high gain + aimed (or omni) on the fixed ground station.**
- **Monopoles need a ground plane** (counterpoise ~λ/4 radius). The fibreglass rocket has none → prefer **half-wave / dipole (ground-plane-independent)** on the rocket. (Grounding the SMA *shell* to the board GND is the coax return — necessary, but it is NOT the antenna's ground plane.)
- Bands to match exactly: **915 MHz = 902–928 MHz** (AU915, not 868/433); 2.4 GHz = 2400–2500; GPS = 1575 MHz L1.
- Termination: **standard SMA male** everywhere. Avoid RP-SMA.

## 4. Link-budget targets (drives the ground antenna choice)
- **Conservative goal: ~4 km, no aiming.** Path loss ~104 dB @ 915 MHz; with 22 dBm TX + ~2 dBi rocket omni + ~2–5 dBi ground omni → ~−77 dBm received vs SX1262 sensitivity ~−129 dBm (SF9/BW125) = **~50 dB margin.** An **omni ground antenna is plenty** — no Yagi/aiming needed. Elevation/LoS is the main lever.
- **Stretch goal: ~10 km.** Path loss ~112 dB; still large margin, but this is where a **Yagi (aimed, +8 dB ≈ 2.5× range)** on the ground earns its keep.
- Current direction: **build for the conservative no-aim 4 km first (omni both ends), keep a Yagi as a later upgrade** for 10 km.

## 5. Current shortlist / decisions so far
Working from a Linx ANT-9xx (916 MHz) DigiKey list; SMA-male only.

**Rocket LoRa (915) — DECIDED:**
- **ANT-916-CW-HW-SMA** — half-wave straight rigid whip, ~120 mm, ~1.2 dBi omni, **no ground plane needed** → **primary flight antenna.**
- **ANT-916-CW-RH-SMA** — quarter-wave straight, ~51 mm, −1.3 dBi, **needs a ground plane** → **spare / for a metal-mount only** (not ideal on fibreglass).

**Ground station LoRa (915) — DECIDED (no-aim, 4 km):**
- **ANT-916-CW-HW-SMA** — same half-wave omni as the rocket, vertical on a pole, elevated. Reusing one part number for both ends (single spare pool, known good, ground-plane-independent). ANT-916-OC-LG-SMA tilt whip dropped — not needed.
- Higher-gain omni option (future, still no aiming): a **915 MHz collinear (~5–8 dBi)**.
- 10 km upgrade: a **915 MHz Yagi (~8–12 dBi, aimed)** — not yet selected.

**2.4 GHz (ESP) — TODO:** rigid whip (rocket, secured internally) / standard-SMA duck (ground). **Standard SMA, not RP-SMA.** Note: 2.4 GHz is only used on the pad (BLE arming/config) and post-landing (Wi-Fi log download) — it's out of range in flight — so it's lower priority, but the antenna still rides through boost so keep it rigid/secured on the rocket.

**GPS — TODO:** an **active ceramic patch antenna**, SMA male, **3.3 V bias-compatible** (most accept 2.7–5.5 V), **rigid** (solid patch — no pole/monopole for GPS: wrong polarisation). Mount flat on a small ground plane under an RF window (nosecone). u-blox ANN-class or equivalent.

## 6. Jumpers / cables needed
- **U.FL → U.FL jumpers ×2** (E22 + ESP module → onboard relay U.FL). U.FL is fragile (~30 mates) — buy spares, strain-relief after final mate.
- **U.FL → SMA-female pigtails ×2** — fallback path (module U.FL straight to antenna).
- **SMA male ↔ female RG316 extensions** — routing SMA to a bulkhead / extending.
- All standard SMA (not RP-SMA).

## 7. Sourcing (Australia)
- **Core Electronics** (core-electronics.com.au) — 915 antennas, active GPS, U.FL/SMA cables; fast local.
- **IoT Store Australia** (iotstore.com.au) — AU915 LoRa antennas incl. Yagis/collinears.
- **Jaycar / Altronics** — walk-in; 2.4 GHz ducks, SMA cables/adapters.
- **Mouser AU / DigiKey AU** — exact specced parts (Linx, Taoglas, u-blox, Amphenol) with datasheets.
- **AliExpress** — cheapest for jumpers/pigtails and generic antennas; slow, buy spares.

## 8. Open questions to help with
1. ~~Finalise the ground-station 915 antenna~~ — **DONE: reusing ANT-916-CW-HW-SMA (same as rocket).** Optional later: an AU omni collinear (~5–8 dBi) or a **915 MHz Yagi** for the 10 km upgrade.
2. Pick the **2.4 GHz antenna** (standard SMA): rigid for rocket, duck for ground.
3. Pick the **active GPS ceramic patch** (SMA male, 3.3 V-bias compatible, AU-available).
4. Confirm final **rocket mounting** (internal axial, RF-transparent section) and that the **CW-HW half-wave** is the right primary.
5. Sanity-check all chosen parts are **standard SMA male**, correct band, and (rocket) rigid + omni + ground-plane-independent.

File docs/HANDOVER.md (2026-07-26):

# Project OZONE — Handover / Project Status

Start-here doc for the OZONE senior flight computer + telecom + ground station.
Points to the detailed references; captures current state, findings, and the
pre-flight to-do. Last major work: 2026-07 (SD bring-up, FCD telecom protocol,
ground station, noise-robust apogee).

## 1. Repo map

| Path | What |
|---|---|
| `v1.0/`, `v0.0/` | KiCad — the flight computer board (v1.0 = fabbed) |
| `ozone_telecom/` | KiCad — the telecom radio daughterboard (not yet fabbed) |
| `firmware/ozone-fw/` | **STM32L452 flight firmware** — see `firmware/ozone-fw/FIRMWARE.md` |
| `firmware/ozone-telecom-fw/` | **ESP32-S3 telecom hub** (PlatformIO) — FCD relay + dual-SD backup |
| `firmware/tools/gcs/` | Python TUI ground console (predecessor) |
| `firmware/tools/web-dashboard/` | vanilla no-build FCD dashboard (fallback) |
| `ground/web/` | **Next.js ground station** (`/` dashboard, `/protocol`, `/builder`) |
| `docs/` | this file + the references below |

**Key reference docs:** `firmware/ozone-fw/FIRMWARE.md` (onboard code),
`docs/fcd-protocol.md` (the self-describing protocol), `docs/telecom-command-protocol.md`
(fire modes + architecture), `docs/fcd-implementer-prompts.md` (paste-into-AI board
prompts), `docs/antenna-selection-handover.md` (RF/antenna), `docs/ERRATA.md`.

## 2. Build / flash / run

```bash
# --- STM32 flight firmware ---
GCC=/Applications/STM32CubeIDE.app/Contents/Eclipse/plugins/*gnu-tools*/tools/bin
CLI=/Applications/STM32CubeIDE.app/Contents/Eclipse/plugins/*cubeprogrammer*/tools/bin/STM32_Programmer_CLI
cd firmware/ozone-fw/Debug && PATH="$GCC:$PATH" make all      # NB: default goal is `clean`, use `all`
"$CLI" -c port=SWD mode=UR -d ozone-fw.elf -v -rst            # flash via ST-Link (SWD)

# --- Web ground station ---
cd ground/web && pnpm install && pnpm dev                     # http://localhost:3000

# --- ESP32 telecom hub (PlatformIO) ---  (board not fabbed yet)
cd firmware/ozone-telecom-fw && pio run
```
Talk to the board over USB-C CDC (`/dev/cu.usbmodem*`, 115200) with pyserial or the
web dashboard (Web Serial, auto-detects VID 0x0483/PID 0x5740).

## 3. Architecture in one paragraph

The STM32 flight computer speaks a self-describing text protocol (**FCD/1**) over
**USB-C CDC** and **USART2** (header J5). On `whoami` it emits a JSON descriptor and
the ground station auto-builds its whole UI from it. USART2 goes to the **ESP32-S3
telecom hub**, a transparent relay that fans FCD out to **WiFi + BLE + LoRa** and
logs a **backup copy of the flight** to its own microSD. Two SD cards = two
independent flight records (FC `OZONE*.CSV` + telecom `TCM*.LOG`).

## 4. Validation status (READ before trusting anything for flight)

**Proven on hardware:** SD mount + CSV logging; sensor bring-up (2×MS5611 + H3LIS +
LIS3DH on SPI1); USB-C FCD streaming (reliable, uncorrupted); whoami descriptor;
identify (blink+beep); subsystem-health telemetry; analog pyro continuity (reads
when the pyro rail is energised); orientation calibration.

**Written / builds clean but NOT hardware-validated:** USART2 telecom link (same
code path as USB, untested until a hub/adapter is attached); **live pyro FIRING**
(bench never had a pyro pack — arming/continuity/pins are in but no charge has ever
fired); the new noise-robust apogee logic (host-sim-verified only); the ESP hub
firmware (board not fabbed); flight state machine over a real flight profile.

**Not done:** flashed as Debug build (not Release); flight thresholds uncalibrated.

## 5. Major findings & fixes this session

- **SD card would not mount — root cause was firmware, not hardware.** CubeMX
  `BSP_SD_Init` gated `HAL_SD_Init` on the unreliable PC3 card-detect. Fixed by
  overriding `BSP_SD_IsDetected`→present. (The card is FAT32, not exFAT.)
- **ERR-007: the whole pyro pin block + pyro-battery ADC channel in the firmware
  `.ioc` were STALE** — matched neither v0.0 nor v1.0. Corrected via direct
  `ozone_hal.h` overrides (regen-safe). Continuity is an **analog divider on ADC
  pins (PA0/PA1)** — read via ADC + threshold, not digital. This **obsoletes
  ERR-002**. ⚠️ The `.ioc` still needs syncing, and `docs/ERRATA.md` needs the
  ERR-007 entry.
- **Apogee could deploy on ASCENT under baro noise.** The old detector voted on the
  sign of a noisy velocity derivative. Replaced with a **rolling-average
  peak-drop** detector (+ smoothed velocity + time-to-apogee). Host sim: zero
  ascent misfires at ±0.8/±5/±15 m noise (all misfired before at ≥±5 m).
- **USB CDC streaming was corrupt/dropping.** `usb_write` aliased a transient
  buffer into the async CDC transfer and dropped-on-busy. Fixed with an 8 KB TX
  ring (copy + drain-when-idle).
- **Calibrated `imu` orientation** for this board baked into the descriptor:
  `map:[+x,-y,+z], up:+y` (from the dashboard's calibration wizard).
- Added **flight EVENTS** (LAUNCH/APOGEE/DEPLOY/PYRO/LANDED) and **dual-SD backup**.

## 6. Pre-flight to-do (the real remaining work)

1. **Calibrate `ozone_config.h`** (each = reflash): VBAT/pyro divider ratios vs DMM;
   `OZONE_CONT_THRESH_V` with a real pack; `OZONE_APOGEE_DROP_M`/`DEBOUNCE_N`;
   launch/apogee/lockout/main thresholds; pyro fire-pulse ms; buzzer resonance.
2. **Ground-test-fire BOTH channels** with the ERR-007-corrected firmware — the
   fire path has never actually fired. Validate continuity + `cont_cleared`.
3. **Replay real flight logs** — `flight_00X/*.bin` (RKTLOG binaries, backed up to
   `~/Documents/avionics-sd-backup-2026-07-23/`) are actual flights; decode the
   format and run them through `flight.c` to validate apogee on genuine data.
4. **Sync the `.ioc`** to the ERR-007 pin map; add the ERR-007 entry to `ERRATA.md`.
5. **Build a Release config** for flight (currently Debug/-O0).
6. Consider **per-channel e-match redundancy** (single e-match today).
7. **Telecom**: fab the board; verify the FC↔hub UART pins (ESP firmware placeholders)
   and the microSD FSPI bus; then validate the USART2 link + LoRa range.
8. **Security**: a plaintext GitHub token is in local `.git/config` remote URL —
   scrub with `git remote set-url` + rotate on GitHub.

## 7. Connectors & cables (for ordering)

- **FC↔telecom UART link is a connector MISMATCH:** FC `J5` = Molex **PicoBlade**
  1.25 mm 4-pin (GND/TX/RX/3V3); telecom `J9` = JST **GH** 1.25 mm 3-pin
  (GND/OZONE_TO_TELECOM/TELECOM_TO_OZONE). Not cross-compatible — make a spliced
  cable (PicoBlade-4 pigtail + GH-3 pigtail, 3 wires) or standardise next rev.
- **Telecom aux** = JST-**GH** 1.25 mm (3-pin: J9 FC-link/J10 power/J11 servo/J13;
  4-pin: J12 I²C). Buy the **elechawk GH1.25 pre-crimped kit** (covers 3+4-pin,
  spares). GH ≈ the Pixhawk connector → drone shops / LCSC / element14, NOT DigiKey.
- **FC** = Molex PicoBlade for J5; Phoenix 3.5 mm screw terminals for pyro/battery
  (bare wire); Samtec 1.27 mm 10-pin for SWD; microSD socket; USB-C.
- **Antennas** (see `antenna-selection-handover.md`): SMA edge = board female →
  antennas must be **SMA male, NOT RP-SMA**. Selection so far:
  **ANT-916-CW-HW-SMA** half-wave omni (both rocket + ground), U.FL↔U.FL jumpers ×2,
  active-antenna-capable GPS port; 10 km-range Yagi TBD.

## 8. Fire modes (safety) — quick note

Four selectable pyro fire modes (`param fire_mode`, default `session`): `safe`
(per-fire nonce), `session` (flight password), `hot` (rolling token, 1-key
emergency), `direct` (armed→fire). The **external key switch is the non-bypassable
hardware gate in all modes.** Full detail: `docs/fcd-protocol.md` §7.

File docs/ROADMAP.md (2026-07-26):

# Project OZONE — Hardware Roadmap

Planned hardware revisions beyond the fabricated **rev 1.0**. Detailed
root-cause/fix writeups for rev-1.0 issues live in [`ERRATA.md`](ERRATA.md);
this file is the forward-looking summary of what each future board should add.

Versioning follows the repo convention (see top-level `README.md`): each rev is
its own self-contained folder. Next board = **rev 1.1**; the bigger comms
overhaul = **rev 2.0**.

---

## Rev 1.1 — "fix-and-polish" + expansion (next fab)

Originally scoped as a drop-in errata pass. **Expanded (2026-07-07)** to also
absorb the pin-hungry changes that were going to force an MCU swap anyway for
rev 2.0 — see "MCU upgrade" below. Two work streams in one board so the
silicon only changes once.

### A. Errata fixes (unchanged from original scope)

1. **Buzzer — make it actually loud.** Pick ONE:
   - **Add a ~1 kΩ discharge resistor across the BZ1 pads** (parallel with the
     piezo). This is the bench-proven fix already bodged onto rev 1.0 — just put
     it on the schematic + BOM so it ships by default. The piezo (CUI
     CPT-9019S-SMT) is a capacitor; with no discharge path the low-side FET only
     charges it once per edge → faint click. RC ≈ 12 µs with 1 k ≪ the 125 µs
     half-period at 4 kHz, so it fully swings 0↔3.3 V each cycle. **Do NOT** add a
     flyback diode (that's for inductive buzzers). *(ERR-006)*
   - **Or swap the part** for a louder / self-driving (magnetic, built-in-drive)
     buzzer if a discharge-resistor fix isn't enough for recovery audibility.
     Then drive from 5 V/VBAT or push-pull (BTL) from two GPIOs to exploit the
     25 Vp-p rating. *(ERR-006)*

2. **Program over ST-Link (SWD) OR USB-C — both paths, confirmed requirement
   (2026-07-07).** Today USB-C is console + log download only — flashing is
   SWD-only because **BOOT0 (PH3/pin60) is tied to GND with no jumper**, so the
   ROM USB-DFU bootloader is unreachable. Fix in hardware:
   - **Break BOOT0 from GND and add a momentary push-button, BOOT0 → 3V3**
     (keep the existing 10 k as the pull-down so default boot is still from
     flash without the button held). Confirmed 2026-07-07: **buttons, not
     just a jumper/test point** — needs to be operable by hand with no tools.
   - **Add a second momentary push-button on NRST → GND** (standard STM32
     reset-button pattern: switch + small ~100 nF debounce cap to GND; NRST
     already has its internal pull-up). Rev 1.0 has **no onboard reset
     button today** — NRST is only reachable via the SWD header (J1) or a
     power cycle, so this is new, not a fix. Needed for the DFU entry sequence
     below and for general bench use without an ST-Link attached.
   - Together these give the standard **BOOT+RESET dev-board sequence**: hold
     BOOT0, tap RESET, release BOOT0 → board comes up in ROM USB-DFU with
     **zero tools** (no ST-Link, no debugger) → flash with STM32CubeProgrammer
     / `dfu-util` over USB-C. **No firmware support needed** — works even on a
     bricked board.
   - The USB data path is already correct (PA11/PA12 ↔ USBLC6 U8 ↔ USB-C J3, CC
     5.1 k Rd), so this is purely the BOOT0 strap. *(ERR-007)*
   - *Firmware alternative (no PCB change, but weaker):* add a `usb_cli` command
     that jumps to system memory (`0x1FFF0000`) → ROM DFU comes up over USB.
     Needs working firmware to trigger, so it can't recover a bricked board —
     SWD stays the recovery path. Worth adding regardless for convenience.
   - **Keep the SWD header (J1: SWDIO/SWCLK/SWO/NRST/3V3/GND) exactly as-is** —
     it stays the ST-Link path and the only way to recover a board with a
     corrupted USB stack/bricked DFU, so USB-C is additive, not a replacement.
   - **Re-verify on the L4R5 MCU swap (§B.1):** BOOT0, USB OTG FS pins
     (PA11/PA12), and the SWD pins (PA13/PA14/PB3) all exist on the L4R5 but
     land on **different physical pin numbers** on the LQFP144 package than on
     the old LQFP64 — re-check the datasheet pinout table and update the
     schematic/CubeMX pin assignment, don't assume the same pin numbers.

3. **Hardware-PWM buzzer pin** — move the buzzer FET gate off PB9 (no timer) to a
   timer-capable pin (PA15→TIM2_CH1 or PB4→TIM3_CH1), freeing the CPU from the
   software-PWM ISR. *(ERR-001)*

4. **Analog pyro continuity** — move PYRO1/2_CONT off PC6/PC7 (not ADC-capable)
   to ADC pins (PA4→IN9, PA0→IN5) for true voltage readback instead of go/no-go.
   *(ERR-002)*

5. **SDMMC pull-ups** — add 47 k to 3V3 on D0–D3 + CMD so the SD clock can run
   full-speed instead of the throttled ClockDiv workaround. *(ERR-004)*

6. **Doc cleanup** — correct the connector tables (USB-C = console + log
   download, not firmware update) and the TIM17 reference. *(ERR-003, ERR-007)*

### B. Demo-board expansion (added 2026-07-07, Dash's requirements)

Purpose: turn rev 1.1 into a **demo/teaching board** — cheaper redundant
sensors, more pyro channels to show off staged deployment, and expansion
headroom for radios — without touching the flight-proven sensor stack
(SPI1: dual MS5611 + H3LIS331DL + LIS3DH stays exactly as-is).

1. **MCU upgrade — L452 (LQFP64) is out of pins.** Adding a 2nd SDMMC, 2 more
   pyro channels, 2 more sensors, and a real expansion header does not fit in
   the ~51 usable GPIO on the current STM32L452RET6, even after the ERR-001/
   ERR-002 pin frees. Rather than swap silicon again for rev 2.0's LoRa/BLE/GPS
   (roadmap already flagged that as tight), **do the MCU swap once, now**, sized
   for both rev 1.1 and rev 2.0 needs.
   - **Recommended: STM32L4R5ZIT6** (LQFP144, same L4 family/toolchain/HAL
     generation as the L452 so `ozone_hal.c` porting is mostly pin renumbering,
     not a rewrite). Gives: **2× SDMMC** (true dual hardware SD, not one real +
     one bit-banged), **3× SPI**, **4× I2C**, **3× USART + 2× UART + LPUART**,
     ~114 GPIO, 2 MB flash / 640 KB RAM (miles of headroom over the 89 KB/14 KB
     rev-1.0 firmware footprint).
   - Cheaper fallback if L4R5 is hard to source: **STM32L476VGT6** (LQFP100, 1×
     SDMMC only — 2nd SD would need to fall back to SPI mode, see below).
   - Action: re-run CubeMX against the new part, remap `ozone_hal.h` pin labels,
     re-check the CMSIS "copy only necessary files" gotcha from the last regen.
   - **This is a bigger change than a drop-in rev** — budget real bring-up time
     (new footprint, new decoupling/BGA-adjacent routing if QFN, re-verify all
     AF mappings). Flagged so it doesn't get scoped like the pure-errata items.

2. **Dual redundant locking SD cards.** Two full-size **SD card sockets with a
   hinged push-to-close latching lid** (insert card, close the door, it
   physically locks shut — not a spring push-push microSD socket). This is a
   distinct connector family from the current microSD holder.
   - **Open item — need a specific part.** Search terms for LCSC/Digikey:
     "SD card connector, hinge type, push-push with lock" or "SD card socket
     SIM/SD combo hinged". Candidates to pull datasheets on: **Amphenol
     GSD1-8G-something / Attend 112B series / TE 2041131-x hinged SD
     sockets** — need to confirm exact part + footprint together before
     committing to the KiCad library.
   - Wire both to the L4R5's **SDMMC1** and **SDMMC2** (4-bit each) for true
     parallel/redundant logging — not one SDMMC + one SPI-bitbanged card.
   - Firmware: `logging.c` needs a second FatFs volume + a redundancy policy
     (mirror both cards? primary + backup? round-robin?) — **decide this
     before writing it**, it changes the API shape.

3. **Demo sensors — dual-redundant, cross-brand pair, for 4 baros / 4 accels
   board-wide (added 2026-07-07, spec'd to 3,000 ft / 16 g on 2026-07-07).**
   Kept off SPI1 deliberately so the existing flight sensor stack/firmware is
   untouched. Counting the flight stack (2× MS5611 + H3LIS331DL + LIS3DH =
   2 baros + 2 accels), doubling the demo sensors gets to the target 4-and-4.
   Each demo pair is **two different brands** (so a bad batch/part-specific
   erratum can't take out both units at once) but **the same communication
   protocol (I2C)** across the pair, so the wiring/bus design stays identical
   regardless of which unit is populated:
   - **Pressure ×2, different brands:** Bosch **BMP390** + STMicroelectronics
     **LPS22HB** — both I2C (also SPI-capable if ever needed), both ~$2–5.
     Range: BMP390 300–1250 hPa, LPS22HB 260–1260 hPa — 3,000 ft is only a
     ~908 hPa reading (vs. ~1013 hPa at sea level), so **both cover it with
     huge margin**, nowhere near their floor. 2× MS5611 + BMP390 + LPS22HB =
     **4 baros**.
   - **Acceleration ×2, different brands:** Analog Devices **ADXL345**
     (±16 g, I2C/SPI, ~$2–4) + Bosch **BMA400** (±16 g, I2C/SPI, ultra-low-power,
     ~$1–2) — both hit the **16 g** spec exactly at their top range setting.
     H3LIS331DL + LIS3DH + ADXL345 + BMA400 = **4 accelerometers**.
   - **Bus topology — two independent I2C buses, not one shared bus.** Rather
     than stack all 4 demo parts on one I2C2 (which was the original plan),
     split into **two full redundant sensor sets, each on its own bus**:
     - **I2C2:** BMP390 + ADXL345 (set A)
     - **I2C3:** LPS22HB + BMA400 (set B)
     This way a single bus fault (stuck SDA/SCL, ESD event, cold joint, address
     conflict with a future addon) only takes out one *complete* baro+accel
     set, not both readings of one sensor type — which is the actual point of
     "redundant" for a demo. Cost: 2 extra GPIO (I2C3 SDA/SCL) vs. the
     single-bus plan — trivial on the L4R5's 4× I2C peripherals and ~114 GPIO,
     wasn't worth it on the pin-starved L452 but is now. No address-select
     strapping needed since each part is alone with its own bus (default
     address is fine).
   - Firmware: `sensors.c` needs a redundancy/voting policy across the two
     sets (median-of-2? flag-on-mismatch? same question as the dual-SD policy
     in item 2) — worth deciding both together since they're the same shape
     of problem.

4. **Pyro channels: 2 → 4.** Same topology as rev 1.0 per channel (opto-isolated
   PC817 → low-side AO3400A N-FET, shared AO3401A arm P-FET off the separate
   pyro battery) — just replicate the fire-GPIO + continuity pair twice more.
   With the L4R5's ADC reaching far more pins, all 4 continuity lines can be
   true analog readback from day one (no ERR-002-style workaround needed).
   GPIO cost: 4× fire + 4× continuity-ADC + 1 shared arm = 9 pins (vs 5 today) —
   trivial on the new part.

5. **Expansion / addon connector(s) — for GPS, LoRa, Bluetooth modules later.**
   Per your note: **not bare 0.1" pin headers** — you want something that
   won't get plugged in backwards on a board other people will handle. Proposed
   shape (confirm before layout):
   - **One shared "radio/GPS" expansion connector**, keyed and locking
     (**JST-GH 1.0 mm pitch** is the common low-profile keyed choice for this —
     shrouded, polarized, cheap, hand-solderable), broken out with everything a
     typical module needs so LoRa (SX1262-class), GPS (u-blox MAX-M10-class),
     and a BT/BLE UART module can each be wired up without a respin:
     - 1× dedicated **SPI** (SPI2 or SPI3 — NOT SPI1) + 2–3 spare GPIO (IRQ/BUSY/
       RESET) → LoRa
     - 1× dedicated **UART** → GPS
     - 1× dedicated **UART** → BT/BLE module
     - 1× spare **I2C** (separate from the demo-sensor I2C2) for anything I2C
     - 3V3, VBAT (for modules needing >3.3 V or wanting to sense battery), GND
   - Could be one big connector or three small module-specific ones — **decide
     once you've picked actual GPS/LoRa/BLE part numbers**, since pinout
     order should match the chosen breakout/module footprints where possible.
   - This is exactly the pin budget rev 2.0 already flagged as tight on the
     L452 — the L4R5 swap in item 1 is what makes this section fit.

6. **Power to the expansion connector(s) — needs more than just tapping 3V3
   (flagged 2026-07-07).** Signal pins aren't the only thing the addon
   header needs; the existing power chain (LiPo → reverse-prot P-FET → 1 A
   polyfuse → TPS63060 buck-boost @3.6 V → SPX3819 LDO @3.3 V, which the whole
   rev-1.0 board runs from) was sized for the **old** load (1 MCU + 4 flight
   sensors + 2 pyro opto/FET gates). Everything added in this rev stacks on
   top of it: MCU swap to a bigger/hungrier L4R5, dual SD (two cards drawing
   write-current simultaneously if mirrored), 4 demo sensors, 4 pyro channels'
   opto/gate drive, **plus** whatever gets plugged into the expansion
   connector(s). Open items to resolve before finalizing the power sheet:
   - **Redo the current budget from scratch**, don't assume rev-1.0 headroom
     carries over. Rough shape of the new loads: LoRa TX bursts ~120 mA
     @+20 dBm (spiky, sub-ms), GPS module ~25–50 mA acquisition, BLE module
     ~10–20 mA with its own TX spikes, a 2nd SD card writing concurrently, plus
     the L4R5 itself likely pulling more than the L452 at similar clock. Check
     this total against both the **TPS63060's rated output current** and the
     **SPX3819 LDO's current rating** — the LDO stage in particular is the
     one most likely to run out of headroom first, since everything downstream
     of it shares one regulator today.
   - **Consider giving the expansion connector(s) their own regulator/rail**
     instead of tapping the shared MCU/sensor 3V3 directly. Two reasons: (1) a
     LoRa TX current spike sagging the shared 3V3 rail risks a brown-out reset
     or corrupting an analog baro/accel reading at the exact moment you're
     transmitting; (2) it lets you **gate power to unpopulated addon slots**
     (a GPIO-controlled P-FET load switch per connector) so a module that
     isn't installed — or one that's hung/misbehaving — doesn't draw quiescent
     current or need a full board power-cycle to reset. Cheap to add (one
     P-FET + one GPIO per addon rail), and useful for a demo board that will
     get modules swapped in and out a lot.
   - **Local bulk capacitance right at each connector** (100–220 µF) for the
     LoRa/GPS TX current spikes regardless of which rail they're on — same
     point already flagged in the rev-2.0 LoRa section, just make sure it's on
     the expansion connector footprint itself, not just "somewhere on the
     board."
   - **Expose raw VBAT (unregulated) as well as regulated 3V3** at the
     connector (already in item 5's pin list) — some modules run their own
     onboard 3.3 V/5 V regulator and would rather take raw battery than be
     double-regulated through the board's LDO.
   - **Re-check the 1 A polyfuse rating** against the new worst-case combined
     current (MCU + sensors + dual SD + both radios transmitting at once,
     even if that's a rare overlap) — don't assume it still has margin.
   - This needs an actual number-by-number budget spreadsheet once part
     numbers for the LoRa/GPS/BLE modules are picked (item 5) — flagging the
     shape of the problem now so it doesn't get missed when the schematic
     gets drawn.

7. **Doc/BOM follow-up once parts are chosen:** update this roadmap's pin table,
   `ozone_hal.h`, the BOM, and `ERRATA.md` cross-references once the SD holder,
   expansion connector, and MCU final part numbers are locked in.

---

## Rev 2.0 — wireless comms + position (LoRa, Bluetooth, GPS)

Goal: add **long-range LoRa telemetry**, **native Bluetooth**, and **on-board
GPS** so pre-flight checks, live downlink, and position/recovery don't depend on
a tethered UART/USB or the bolt-on BT module.

> Early planning — capture intent now, refine when rev 1.1 is proven.
> **LoRa role still TBD** — decide whether it's the primary downlink or a backup
> before committing layout/RF effort (see open questions). For now: include it,
> scope its role later.
>
> **Pin budget resolved by rev 1.1 (2026-07-07):** the MCU swap to STM32L4R5
> and the keyed expansion connector(s) in rev 1.1 §B.5 already reserve a free
> SPI (LoRa), 2 free UARTs (GPS + BLE module), and a free I2C for this section.
> Rev 2.0 is now mostly "populate the connectors with real modules + antennas +
> RF layout", not a fresh pin-budget fight.

### LoRa (long-range downlink)
- **Module candidates:** SX1276/78 (sub-GHz, classic, lots of libs) or **SX1262**
  (newer, lower power, better link budget) — or an integrated module
  (RFM95W / Ebyte E22) to skip the RF layout. Module-first is the safer call for
  a student project unless someone owns the RF design.
- **Band:** **915 MHz** ISM for Australia (AS923 / AU915) — confirm legal channel
  plan and antenna for the launch site.
- **MCU interface:** SPI + a couple of GPIOs (DIO IRQ, NRST, optional BUSY for
  SX1262) — uses the dedicated LoRa SPI + GPIOs already reserved on the rev-1.1
  expansion connector (§B.5), not SPI1 (still flight-sensor-only).
- **Antenna:** u.FL/SMA + matching; keep RF away from the digital/pyro section
  and the metal airframe; plan ground-plane and keep-outs early.
- **Power:** LoRa TX bursts are spiky (~120 mA @ +20 dBm on SX1262) — verify the
  TPS63060 buck-boost headroom and add local bulk capacitance at the module.

### Bluetooth (short-range pre-flight)
- **Decide integrated vs module:**
  - **Module (lowest effort):** keep a UART BLE module (e.g. an nRF52-based
    module) on the existing UART header path — minimal redesign, just make it a
    proper footprint instead of a flying header.
  - **Integrated MCU (bigger change):** move to an MCU with built-in BLE
    (STM32WB55 = Cortex-M4 + BLE radio, fairly close to the L452 toolchain; or an
    nRF52840). This is a **processor swap** → effectively a new flight computer,
    not a tweak. Only do this if BLE is core, not nice-to-have.
- **Recommended path:** keep the L452 + a BLE *module* for rev 2.0 to limit risk;
  reserve the STM32WB/nRF integrated route for a later "clean-sheet" board.

### GPS (position / recovery)
- **Module candidates:** u-blox **MAX-M10** (low power, GPS+GNSS, easy to source)
  or NEO-M9N for more performance. Module-level keeps RF/layout simple.
- **MCU interface:** UART (NMEA/UBX) is simplest; I2C also available on u-blox.
  Budget a spare UART — the rev-1.0 UART header (USART2, PA2/PA3) is currently
  the Bluetooth path, so GPS likely needs its **own UART** (USART1 PA9/PA10 or
  LPUART) or shares the bus with care.
- **Antenna:** active patch antenna + LNA bias; needs clear sky view and
  separation from the LoRa/BLE radios — fold this into the rev-2.0 RF survey.
- **Altitude caveat:** standard GPS modules are **CoCom-limited (lock drops above
  ~18 km and/or >515 m/s)** — for a 30 km sounding rocket confirm the module has
  a selectable **"airborne <4g" dynamic model** and check the altitude/velocity
  limits, or GPS will drop out at apogee exactly when you want it.
- **Role:** primarily recovery + post-flight track; not a flight-control sensor.

### Rev 2.0 open questions (resolve before layout)
- Is LoRa the *primary* downlink (then it needs range-test priority) or backup to
  the existing comms?
- BLE module vs integrated-radio MCU — see trade-off above. Drives whether rev
  2.0 is an incremental add or a redesign.
- ~~Pin/peripheral budget~~ — **resolved**: rev 1.1's L4R5 swap + expansion
  connector reserve SPI/UART/UART/I2C for LoRa/GPS/BLE up front.
- Antenna placement & airframe RF survey (LoRa + BLE + GPS, three antennas) —
  plan co-existence and sky view early.
- GPS dynamic model: confirm the chosen module supports the airborne/high-altitude
  mode so it survives apogee on a 30 km flight.

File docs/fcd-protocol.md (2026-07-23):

# FCD — Flight Computer Descriptor Protocol

**Version:** `fcd/1`
**Status:** Implemented as the OZONE ground-station protocol; OZONE firmware
integration in progress over USART2 (see [`telecom-command-protocol.md`](telecom-command-protocol.md)).
**Audience:** Anyone implementing or driving an FCD-speaking flight computer —
firmware engineers, ground-station developers, other UNSW Rocketry teams.

This document consolidates and supersedes the protocol description previously
split across `firmware/tools/gcs/PROTOCOL.md` and `docs/telecom-command-protocol.md`.
Where those two sources disagree, this document says so explicitly — see
[§11 Open questions / discrepancies](#11-open-questions--discrepancies).

---

## 1. Overview

FCD ("Flight Computer Descriptor") is a small, text-based, board-agnostic
protocol that lets **one** ground station application drive **any** flight
computer. Instead of the ground station hard-coding what buttons, graphs, and
telemetry fields a particular board has, the board **describes itself** the
moment it connects: what to check before flight, what to plot, what settings
are tunable, and what commands it accepts. The ground station reads that
description and builds its entire UI from it.

**Core idea:** the flight computer is the single source of truth for its own
capabilities *and* for flight safety. The ground station is a generic client —
add a sensor or a command in firmware, declare it in the descriptor, and it
appears on every FCD-compatible ground station with no client-side code
changes.

FCD is deliberately cheap to implement: a board needs to do two things to be
minimally conformant — reply to one query with one line of JSON, and stream
telemetry as `key=value` pairs. Everything else (params, actions, pyro
handshakes, command integrity) layers on top of that same line-oriented text
channel.

---

## 2. Transport assumptions

FCD does not care what physical link it rides on. It only assumes:

- **Newline-delimited ASCII/UTF-8 text.** Every message — handshake, telemetry
  sample, log line, command, reply — is exactly one line terminated by `\n`
  (`\r\n` is fine too; trim it on receipt).
- **A byte-stream, not a packet protocol.** No framing, addressing, or
  multiplexing is defined; FCD assumes a single point-to-point link between
  one ground station and one board.
- **No guaranteed ordering or delivery beyond what the link itself provides.**
  Radios and noisy links can drop or garble lines. Telemetry lines are cheap
  and repeat every sample, so a dropped `TLM` line is a non-event. Commands
  that matter (pyro fire) have their own integrity mechanism — see [§8](#8-command-integrity-crc--sequence-numbers).

This is why it runs unmodified over:

- **USB CDC** (virtual serial port) — the common bench/lab link.
- **UART** — e.g. OZONE's USART2 at 115200 8N1, PA2 (TX) / PA3 (RX).
- **Transparent-mode radio** — OZONE's telecom link is an Ebyte E22-900M22S
  LoRa module (915 MHz AU ISM) in transparent-UART mode, so the exact same
  byte stream that works over a wired UART works over the air. LoRa air-rate
  is low (a few kbps), which is why the telemetry *rate* is itself a
  declared, settable param (`tlm_hz`) rather than fixed — a board tunes it to
  fit its link.

No board-specific transport code is needed on the ground-station side beyond
"open this serial device and read/write lines."

---

## 3. Handshake (discovery)

On connect, the ground station sends:

```
whoami
```

The board replies with **one line**, prefixed with a marker so it can be
picked out of any other console output, followed by a compact JSON
descriptor:

```
FCD1 {"p":"fcd/1","name":"PROJECT OZONE", ...}
```

The ground station parses everything after the `FCD1 ` marker as JSON and
configures its entire UI from it (checks list, voltage bars, graphs,
telemetry parser, params panel, action buttons).

**Fallback:** if no `FCD1` line arrives within roughly **1.5 seconds** of
sending `whoami`, the ground station falls back to a built-in profile (a
known board's hard-coded descriptor, or a generic minimal one). This means a
non-conforming or not-yet-updated board still partially works — you get a
plain terminal instead of a rich UI, not a hang.

---

## 4. The descriptor (JSON schema)

Only `p` and `name` are strictly required. Every other field is optional and
degrades gracefully if omitted — this is what makes the protocol
forward-compatible (see [§9](#9-versioning--forward-compatibility)).

| Field | Type | Required | Meaning |
|---|---|---|---|
| `p` | string | **yes** | Protocol id + version, e.g. `"fcd/1"`. Lets the client adapt behaviour per protocol version. |
| `name` | string | **yes** | Board/project title shown in the UI (e.g. `"PROJECT OZONE"`). |
| `sub` | string | no | Subtitle, e.g. team/board description. |
| `fw` | string | no | Firmware version string, free-form (e.g. `"0.1.0"`). |
| `accent` | string | no | UI accent colour hint (e.g. `"cyan"`). |
| `checks` | array of `{id, label}` | no | Preflight checklist items the UI renders as live pass/fail rows. `id` should map to something the board can actually report status for (often surfaced via `TLM` or `LOG`). |
| `rails` | array of `{id, label, min, max, nom?}` | no | Power rails rendered as coloured voltage bars. `id` maps to a telemetry channel name. The client colours green within `[min,max]`, yellow near the edges, red outside. |
| `graphs` | array of `{id, label, unit}` | no | Live channels to plot as scrolling sparklines/graphs — one graph per entry. `id` maps to a telemetry channel name. |
| `tlm` | array of strings | no | Documents the full set of channel names the board streams in `TLM` lines (see [§5](#5-telemetry-stream)). Should be kept in sync with what is actually emitted. |
| `states` | array of strings | no | The flight-state vocabulary (e.g. `["PAD","BOOST","COAST","APOGEE","DESCENT","LANDED"]`), used for labelling/colouring the `state` telemetry value. |
| `params` | array of param objects | no | Tunable settings the console can read (`get`) and write (`set <id> <val>`). See shape below. |
| `actions` | array of action objects | no | Commands the console can invoke via `do <id> [k=v]`. The console auto-renders one button per action. See shape below. |
| `imu` | object `{accel:[x,y,z], up, units, g_rest}` | no | Inertial orientation (see below). `accel` = the three TLM keys carrying the accelerometer axis components; `up` = the board axis reading +1 g at rest; lets a ground station render a 3D orientation view. |
| `caps` | object | no | Capability flags — see below. |

**`params[]` object shape:**

| Field | Type | Required | Meaning |
|---|---|---|---|
| `id` | string | yes | Param identifier, used in `get`/`set`/`PARAM` replies. |
| `label` | string | yes | Human-readable label for the UI. |
| `type` | `"float"` \| `"int"` \| `"bool"` \| `"enum"` | yes | Value type; drives what input widget the console shows and how it parses replies. |
| `value` | matching the declared `type` | yes | Current value at descriptor time (informational; `get` returns live values). |
| `min` / `max` | number | no | Bounds for `float`/`int` types. |
| `values` | array of strings | required for `enum` | The allowed enum values. |
| `unit` | string | no | Unit label shown next to the value (e.g. `"m/s"`). |

**`actions[]` object shape:**

| Field | Type | Required | Meaning |
|---|---|---|---|
| `id` | string | yes | Action identifier, used in `do <id> ...`. |
| `label` | string | yes | Button label. |
| `confirm` | string | no | If present, the operator must type this exact token before the console sends the command (e.g. `"ARM"`, `"FIRE"`). |
| `danger` | bool | no | If true, render the button in red/warning styling. |
| `args` | array of `{id, type, min?, max?, values?}` | no | Arguments the console prompts for before sending, appended as `k=v` pairs. |

**`caps` object fields:**

| Field | Type | Meaning |
|---|---|---|
| `pyro` | int | Number of pyro channels. Drives how many `contN` continuity fields the console expects in telemetry (`cont1..contN`). |
| `arm` | bool | Whether arming is supported at all. |
| `logs` | bool | Whether the board logs to SD (and those logs are downloadable). |
| `telemetry` | bool | Whether the board has a live in-flight downlink. If `false`, the console shows a "logging, disconnect & fly" view instead of live graphs, since there's nothing to stream in flight. **Defaults to `true` if omitted.** |

### Orientation (`imu`)

If the board has an accelerometer, it can declare an `imu` block so the ground
station can draw a live 3D orientation view instead of just a number:

```jsonc
"imu": {
  "accel": ["lo_gx", "lo_gy", "lo_gz"], // the 3 TLM keys for the axis components
  "up":    "+z",                        // board axis pointing skyward at rest (nose-up)
  "units": "g",                         // component units
  "g_rest": 1.0                         // |accel| magnitude at rest
}
```

- Axes are **right-handed**; `up` is the axis that reads `+g_rest` when the
  vehicle stands nose-up on the pad. It **must** match the physical sensor
  mounting (sign included, e.g. `-y`).
- The station derives **tilt** from the gravity vector at rest. This is
  accel-only: there is **no yaw**, and during powered/coast flight the measured
  vector is thrust/drag, not gravity — so label the view "orientation
  (accel-derived)" and treat it as attitude-at-rest, not a full IMU.
- Prefer the **low-g** accelerometer's axes for `accel` (clean 1 g at rest); the
  high-g sensor saturates the resting reading.

### Full annotated example

```jsonc
{
  "p":      "fcd/1",                   // protocol id + version (required)
  "name":   "PROJECT OZONE",           // title (required)
  "sub":    "UNSW Rocketry Senior FC",
  "fw":     "0.1.0",
  "accent": "cyan",

  "checks": [
    {"id": "power", "label": "Power"},
    {"id": "baro",  "label": "Barometers"}
  ],

  "rails": [
    {"id": "vbat", "label": "Main batt", "min": 6.4, "max": 8.4, "nom": 7.4}
  ],

  "graphs": [
    {"id": "agl_m",  "label": "Altitude AGL",  "unit": "m"},
    {"id": "vel_ms", "label": "Vertical vel", "unit": "m/s"}
  ],

  "tlm": [
    "t_ms", "state", "agl_m", "alt_m", "vel_ms", "pressure_pa", "temp_c",
    "hi_g", "lo_g", "vbat", "pyro_v", "armed", "cont1", "cont2"
  ],

  "states": ["PAD", "BOOST", "COAST", "APOGEE", "DESCENT", "LANDED"],

  "params": [
    {"id": "apogee_vel", "label": "Apogee detect vel", "type": "float",
     "value": 3.0, "min": 0, "max": 50, "unit": "m/s"},
    {"id": "vbat_div",   "label": "VBAT divider",       "type": "float", "value": 4.49},
    {"id": "units",      "label": "Altitude units",     "type": "enum",
     "value": "m", "values": ["m", "ft"]}
  ],

  "actions": [
    {"id": "arm",     "label": "Arm pyros", "confirm": "ARM"},
    {"id": "set_led", "label": "Set RGB LED",
     "args": [{"id": "colour", "type": "enum", "values": ["off", "red", "green", "blue"]}]},
    {"id": "fire",    "label": "Ground-test fire", "danger": true, "confirm": "FIRE",
     "args": [{"id": "ch", "type": "int", "min": 1, "max": 2}]}
  ],

  "caps": {"pyro": 2, "arm": true, "logs": true, "telemetry": true}
}
```

---

## 5. Telemetry stream and log lines

### `TLM` — telemetry samples

When streaming is on, the board emits one line per sample: `TLM` followed by
whitespace-separated `key=value` pairs, order-independent, missing keys
tolerated:

```
TLM t_ms=12345 state=BOOST agl_m=412.7 vel_ms=188.1 pressure_pa=96050 temp_c=12.3 hi_g=9.6 lo_g=15.9 vbat=7.81 pyro_v=7.40 armed=0 cont1=1 cont2=1
```

**Type coercion rules** — there are no per-field types in the descriptor
because the value itself tells the parser what it is:

- `state` is always one of the `states` strings declared in the descriptor.
- Booleans are `0` or `1` (e.g. `armed`, `cont1`).
- Everything else is a number (int or float), parsed as such.
- Keys should match the ids listed in `tlm`. `graphs[].id` and `rails[].id`
  are read directly out of the telemetry stream; continuity fields follow
  the pattern `cont1..contN` where `N = caps.pyro`.

### `LOG` — event / error lines

The board may emit log lines at any time, interleaved with `TLM` lines. This
is how the board surfaces faults (boot fault codes, sensor dropouts, SD
errors) to the operator in real time:

```
LOG ERR  SD write failed (FR_DISK_ERR)
LOG WARN baro2 dropout - using baro1
LOG INFO apogee detected (3303 m)
```

**Format:** `LOG <level> <message>`, where `level` ∈ `ERR|WARN|INFO|DEBUG`
(single-letter `E|W|I|D` are also accepted). The ground station streams these
into a live event-log pane, colour-coded by level, with an err/warn counter.

---

## 6. Commands (ground → board)

The ground station drives the board with three line commands; the board
replies on one line. **Unknown commands should reply `ERR`.**

| Send | Meaning | Reply (example) |
|---|---|---|
| `whoami` | Request descriptor | `FCD1 {...}` |
| `get` | Dump all params | `PARAM apogee_vel=3.0` (one line per param, or one line with all — implementation's choice, but be consistent) |
| `set <id> <value>` | Write a param | `PARAM apogee_vel=5.5` or `ERR range` |
| `do <id> [k=v ...]` | Invoke an action | `ACK fire ch1 fired` or `ERR not armed` |

**Reply grammar:**

- `PARAM <id>=<value>` — a param was read or successfully written.
- `ACK <id> [detail...]` — an action was invoked successfully; `detail` is
  free-form context (e.g. `ACK fire ch1 fired`, `ACK arm armed`).
- `ERR [reason]` — the command was rejected; `reason` is free-form and
  intended for the operator, not machine parsing (e.g. `ERR not armed`,
  `ERR range`, `ERR bad_token`).

```
set apogee_vel 5.5         -> PARAM apogee_vel=5.5
do set_led colour=red      -> ACK set_led red
do arm                     -> ACK arm armed
do fire ch=1               -> ERR not armed        (board enforces interlocks)
```

**The board is the source of truth for safety.** It must reject `fire`
unless armed (and the external key switch is closed — see [§7](#7-pyro-fire-mode-handshakes)),
validate `set` against the declared `min`/`max`/`values`, and enforce
whatever flight-state lockouts apply. The ground station adds
operator-side guards on top of this (typed `FIRE`/`ARM` confirmation, red
danger styling, hold-to-fire) but must never be relied on as the only
safety layer — a board must be safe even if driven by a naive or malicious
client.

---

## 7. Pyro fire-mode handshakes

OZONE's pyro system has two channels (`PYRO_CH1`, `PYRO_CH2`; drogue + main).
Firing is gated by three independent layers, from outermost to innermost:

1. **External key switch (hardware, non-bypassable).** Powers the arm P-FET
   rail. Software cannot fire without it physically closed, in *any* mode.
2. **Software arm + continuity.** `pyro_is_armed()` and per-channel
   continuity (e-match presence) must both be true.
3. **The selected `fire_mode` handshake** (documented below) — this is the
   *only* thing that changes between modes. It governs the ground↔board
   conversation required before a `do fire` is honoured; it does not weaken
   layers 1 or 2.

**Design principle:** pay the safety cost before the emergency, not during
it. A manual deploy is usually a contingency ("something went wrong, fire
NOW"), so the time-critical step must be fast — achieved by doing
verification work ahead of time, not at the moment of firing.

The mode is chosen with the `fire_mode` param (four values:
`safe` / `session` / `hot` / `direct` — see `pyro_trigger.h`,
`fire_mode_t`). Switching mode clears all in-progress prime/deploy-ready/
session state (re-safes).

### Mode A — `safe` (staged per-fire nonce)

For **planned ground tests**. Two steps per fire, each channel primed
individually:

```
do prime ch=1            -> ACK prime ch1 token=8341 window=10s   (fresh random one-shot token)
do fire ch=1 token=8341  -> ACK fire ch1 fired                    (token match + within window + armed + continuity)
```

A stale, expired, or wrong token returns `ERR` and the window closes (the
token is consumed / cleared). The default prime→fire window is 10 s
(`OZONE_TRIG_SAFE_WINDOW_MS`). Replay- and glitch-proof, but requires two
round-trips per fire — too slow for an in-flight emergency.

### Mode B — `session` (flight-long password)

A single "flight key" is established once, at flight-mode entry, and is
valid for every fire for the rest of the session (no per-fire window):

```
do flight_mode                 -> ACK flight_mode key=51992     (board rolls a random key)
   ...later, in flight...
do fire ch=1 token=51992       -> ACK fire ch1 fired             (session key match; no expiry)
do fire ch=2 token=51992       -> ACK fire ch2 fired             (same key works for the other channel)
```

The ground crew can also supply a chosen key instead of letting the board
roll one (`pyro_trigger_arm_session(supplied, ...)` takes a non-zero
`supplied` value). The key persists until `safe`/`disarm`/mode change, is
**not** streamed in telemetry (unlike the `hot`-mode rolling token — see
below), and is the operator's responsibility to remember/protect. Firing
before a key is set returns `ERR not primed/ready/keyed`.

> The exact `do` command name and argument spelling for entering `session`
> mode is not settled in the source documents — see
> [§11](#11-open-questions--discrepancies).

### Mode C — `hot` (deploy-ready, recommended for in-flight emergency)

The handshake is paid **ahead of time**; the emergency fire itself is a
single keypress:

```
do arm                   -> ACK arm armed              (key switch must be closed)
do deploy_ready ch=1     -> ACK deploy_ready ch1        (one-time confirm; latches deploy-ready)
   ... board now streams a live rolling token in telemetry: TLM ... dtok1=5567 ...
   ... token rotates every ~4 s; the fire window auto-refreshes while deploy-ready and armed ...
do fire ch=1 token=5567  -> ACK fire ch1 fired          (ground station binds this to ONE guarded
                                                          hotkey that auto-fills the current token)
```

Fast (one key at the moment of truth) **and** replay-safe (must carry the
currently-live rolling token, which changes every rotation period). If the
board drops out of armed (key switch opens) while deploy-ready, it
automatically re-safes that channel. `do safe` / `do disarm` also exits
deploy-ready and clears state.

### Mode D — `direct` (fastest, least safe)

Once armed (key switch closed) and continuity is present, fire immediately —
no token, no prior handshake step:

```
do fire ch=1             -> ACK fire ch1 fired
```

Relies solely on the key switch, software arm, and continuity check (plus
the optional command CRC, to catch a garbled line — see [§8](#8-command-integrity-crc--sequence-numbers)).
The ground station is expected to guard this operator-side with a
hold-to-fire interaction. Use only if the team has explicitly accepted the
reduced protection against a replayed or spoofed `do fire` line.

### Mode comparison

| Mode | Setup steps before fire | Time-to-fire at the moment of truth | Replay-safe? | Best use |
|---|---|---|---|---|
| `safe` | `prime` (per channel, per fire) | 1 command (`fire` + token) | Yes — one-shot token, 10 s window | Planned ground tests |
| `session` | `flight_mode` (once per flight) | 1 command (`fire` + session key) | Partial — key is long-lived, not per-fire; protects against garble/random replay but not a captured key | Normal flight arming — pay the cost once, fire fast for the rest of the flight |
| `hot` | `arm` + `deploy_ready` (per channel, once) | 1 command (`fire` + current rolling token) | Yes — token rotates every ~4 s, window is 2 rotations wide | **Recommended for in-flight emergency manual deploy** |
| `direct` | `arm` only | 1 command (`fire`, no token) | No — any well-formed `do fire` line fires | Bench/lab testing only, accepted-risk teams |
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

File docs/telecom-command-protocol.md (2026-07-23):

# OZONE Telecom — Command & Telemetry Protocol (firmware side)

Status: **in progress** (2026-07-23). Implements the `fcd/1` protocol
(`firmware/tools/gcs/PROTOCOL.md`) in OZONE firmware over **USART2**, so the
existing `gcs` ground station drives the board over the radio link.

## Link
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

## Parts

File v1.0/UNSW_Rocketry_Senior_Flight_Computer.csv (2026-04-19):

Reference | Qty | Value | DNP | Exclude from BOM | Exclude from Board | Footprint | Datasheet
BZ1 | 1 | Buzzer |  |  |  | Buzzer_Beeper:Buzzer_CUI_CPT-9019S-SMT
C1,C2,C3,C7,C8,C10,C11,C14,C16,C19,C20,C21,C25,C27 | 14 | 0.1uF |  |  |  | PCM_SparkFun-Capacitor:C_0603_1608Metric | https://cdn.sparkfun.com/assets/8/a/4/a/5/Kemet_Capacitor_Datasheet.pdf
C4 | 1 | 4.7uF |  |  |  | PCM_SparkFun-Capacitor:C_0603_1608Metric | https://cdn.sparkfun.com/assets/8/a/4/a/5/Kemet_Capacitor_Datasheet.pdf
C5,C9,C22,C23,C31 | 5 | 1.0uF |  |  |  | PCM_SparkFun-Capacitor:C_0603_1608Metric | https://cdn.sparkfun.com/assets/8/a/4/a/5/Kemet_Capacitor_Datasheet.pdf
C6,C33 | 2 | 10nF |  |  |  | PCM_SparkFun-Capacitor:C_0603_1608Metric | https://cdn.sparkfun.com/assets/8/a/4/a/5/Kemet_Capacitor_Datasheet.pdf
C12,C13 | 2 | 27pF |  |  |  | PCM_SparkFun-Capacitor:C_0603_1608Metric | https://cdn.sparkfun.com/assets/8/a/4/a/5/Kemet_Capacitor_Datasheet.pdf
C15,C24 | 2 | 10uF |  |  |  | PCM_SparkFun-Capacitor:C_0805_2012Metric | https://mm.digikey.com/Volume0/opasdata/d220001/medias/docus/4888/TMK212BBJ106KG-T_SS.pdf
C17,C18,C26 | 3 | 22uF |  |  |  | PCM_SparkFun-Capacitor:C_0805_2012Metric | https://mm.digikey.com/Volume0/opasdata/d220001/medias/docus/43/CL21A226MOCLRNC_Spec.pdf
C29 | 1 | 10pF |  |  |  | PCM_SparkFun-Capacitor:C_0603_1608Metric | https://cdn.sparkfun.com/assets/8/a/4/a/5/Kemet_Capacitor_Datasheet.pdf
D1,D2 | 2 | B5819W |  |  |  | Diode_SMD:D_SOD-123
D3,D4,D5,D7,D8 | 5 | Green |  |  |  | LED_SMD:LED_0603_1608Metric
D6 | 1 | 5.1V |  |  |  | Diode_SMD:D_SOD-323
D9,D12 | 2 | SMAJ15A |  |  |  | Diode_SMD:D_SMA | https://www.littelfuse.com/media?itemid=75e32973-b177-4ee3-a0ff-cedaf1abdb93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
D10,D11,D13,D14,D15 | 5 | LED |  |  |  | LED_SMD:LED_0603_1608Metric_Pad1.05x0.95mm_HandSolder
D16 | 1 | LED_RGB |  |  |  | LED_SMD:LED_RGB_5050-6
F2 | 1 | 1A |  |  |  | Fuse:Fuse_1206_3216Metric
J1 | 1 | PYRO_XT60 |  |  |  | Connector_AMASS:AMASS_XT60PW-M_1x02_P7.20mm_Horizontal
J2 | 1 | Micro_SD_Card_Det1 |  |  |  |  | https://datasheet.lcsc.com/lcsc/2110151630_XKB-Connectivity-XKTF-015-N_C381082.pdf
J3 | 1 | BATT_XT60 |  |  |  | Connector_AMASS:AMASS_XT60PW-M_1x02_P7.20mm_Horizontal
J4 | 1 | USB_C_Receptacle_USB2.0_16P |  |  |  |  | https://www.usb.org/sites/default/files/documents/usb_type-c.zip
J5 | 1 | Conn_01x04 |  |  |  | Connector_PinHeader_2.54mm:PinHeader_1x04_P2.54mm_Vertical
J6 | 1 | SWD |  |  |  | Connector_PinHeader_2.54mm:PinHeader_1x05_P2.54mm_Vertical
J7 | 1 | J_PYRO1 |  |  |  | TerminalBlock_Phoenix:TerminalBlock_Phoenix_MKDS-1,5-2-5.08_1x02_P5.08mm_Horizontal
J8 | 1 | J_PYRO2 |  |  |  | TerminalBlock_Phoenix:TerminalBlock_Phoenix_MKDS-1,5-2-5.08_1x02_P5.08mm_Horizontal
JP1 | 1 | RESET_JMP |  |  |  | TestPoint:TestPoint_2Pads_Pitch2.54mm_Drill0.8mm
L2 | 1 | 1µH |  |  |  | Inductor_SMD:L_Coilcraft_XxL4020
Q1,Q3,Q4 | 3 | AO3400A |  |  |  | Package_TO_SOT_SMD:SOT-23 | http://www.aosmd.com/pdfs/datasheet/AO3400A.pdf
Q2 | 1 | DMG2301L |  |  |  | Package_TO_SOT_SMD:SOT-23 | http://diodes.com/assets/Datasheets/DMG2301L.pdf
Q5 | 1 | AO3401A |  |  |  | Package_TO_SOT_SMD:SOT-23 | http://www.aosmd.com/pdfs/datasheet/AO3401A.pdf
R1,R6,R14,R18,R20,R23,R24,R26,R32,R39 | 10 | 10k |  |  |  | PCM_SparkFun-Resistor:R_0603_1608Metric | https://www.vishay.com/docs/20035/dcrcwe3.pdf
R2,R3 | 2 | 5.1k |  |  |  | PCM_SparkFun-Resistor:R_0603_1608Metric | https://www.vishay.com/docs/20035/dcrcwe3.pdf
R4 | 1 | 620k |  |  |  | PCM_SparkFun-Resistor:R_0603_1608Metric | https://www.vishay.com/docs/20035/dcrcwe3.pdf
R5,R12,R13,R28 | 4 | 100k |  |  |  | PCM_SparkFun-Resistor:R_0603_1608Metric | https://www.vishay.com/docs/20035/dcrcwe3.pdf
R7,R16,R22,R25,R30,R33,R34 | 7 | 1k |  |  |  | PCM_SparkFun-Resistor:R_0603_1608Metric | https://www.vishay.com/docs/20035/dcrcwe3.pdf
R8,R21,R27 | 3 | 3.3k |  |  |  | PCM_SparkFun-Resistor:R_0603_1608Metric | https://www.vishay.com/docs/20035/dcrcwe3.pdf
R9,R15,R17 | 3 | 4.7k |  |  |  | PCM_SparkFun-Resistor:R_0603_1608Metric | https://www.vishay.com/docs/20035/dcrcwe3.pdf
R10 | 1 | 0 |  |  |  | PCM_SparkFun-Resistor:R_0603_1608Metric | https://industrial.panasonic.com/cdbs/www-data/pdf/RDN0000/AOA0000C313.pdf
R11,R19,R29 | 3 | 330 |  |  |  | PCM_SparkFun-Resistor:R_0603_1608Metric | https://www.vishay.com/docs/20035/dcrcwe3.pdf
R31 | 1 | 33k |  |  |  | PCM_SparkFun-Resistor:R_0603_1608Metric | https://www.vishay.com/docs/20035/dcrcwe3.pdf
R35 | 1 | 150 |  |  |  | PCM_SparkFun-Resistor:R_0603_1608Metric | https://www.vishay.com/docs/20035/dcrcwe3.pdf
R36,R37,R38 | 3 | 100 |  |  |  | PCM_SparkFun-Resistor:R_0603_1608Metric | https://www.vishay.com/docs/20035/dcrcwe3.pdf
TP1,TP2,TP3,TP4,TP5,TP6,TP7,TP8,TP9,TP10,TP11,TP12,TP13 | 13 | 1.0mm |  |  |  | PCM_SparkFun-Connector:TestPoint-1.0mm
U1 | 1 | STM32L452RETx |  |  |  | Package_QFP:LQFP-64_10x10mm_P0.5mm | https://www.st.com/resource/en/datasheet/stm32l452re.pdf
U2 | 1 | MS5611 #1 |  |  |  | Package_LGA:LGA-8_3x5mm_P1.25mm | https://www.te.com/commerce/DocumentDelivery/DDEController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
U3 | 1 | MS5611 #2 |  |  |  | Package_LGA:LGA-8_3x5mm_P1.25mm | https://www.te.com/commerce/DocumentDelivery/DDEController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
U4 | 1 | LIS3DH |  |  |  | Package_LGA:LGA-16_3x3mm_P0.5mm_LayoutBorder3x5y | https://www.st.com/resource/en/datasheet/cd00274221.pdf
U5 | 1 | H3LIS331DL |  |  |  | Package_LGA:LGA-16_3x3mm_P0.5mm_LayoutBorder3x5y | https://www.st.com/content/ccc/resource/technical/document/datasheet/3e/48/02/c7/a4/e6/41/bb/DM00053090.pdf/files/DM00053090.pdf/jcr:content/translations/en.D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
U6 | 1 | USBLC6-2SC6 |  |  |  | Package_TO_SOT_SMD:SOT-23-6 | https://www.st.com/resource/en/datasheet/usblc6-2.pdf
U7 | 1 | TPS63060 |  |  |  | Package_SON:Texas_S-PWSON-N10_ThermalVias | http://www.ti.com/lit/ds/symlink/tps63060.pdf
U8 | 1 | SPX3819M5-L-3-3 |  |  |  | Package_TO_SOT_SMD:SOT-23-5 | https://www.exar.com/content/document.ashx?id=22106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
U9,U10,U11 | 3 | PC817 |  |  |  | Package_DIP:DIP-4_W7.62mm | http://www.soselectronic.cz/a_info/resource/d/pc817.pdf
Y1 | 1 | 8MHz |  |  |  | Crystal:Crystal_SMD_3225-4Pin_3.2x2.5mm_HandSoldering | https://ecsxtal.com/store/pdf/ecx-32.pdf

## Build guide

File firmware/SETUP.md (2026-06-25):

# OZONE firmware — STM32CubeMX project setup

Target MCU: **STM32L452RET6** (LQFP64). Generate with **STM32CubeMX** (standalone),
then import into **STM32CubeIDE**. Pinout is taken verbatim from the Project OZONE
technical doc, §16.

---

## A. Create the project (CubeMX home)
1. **File → New Project** (or "ACCESS TO MCU SELECTOR").
2. Search part number `STM32L452RET6` → select the LQFP64 row → **Start Project**.

## B. Pinout & Configuration tab

### System Core
- **RCC**: High Speed Clock (HSE) = **Crystal/Ceramic Resonator** → claims PH0/PH1.
  Low Speed Clock (LSE) = Disable.
  Also tick **Clock Recovery System (CRS SYNC)** = via USB once USB is enabled.
- **SYS**: Debug = **Serial Wire** (PA13/PA14). Timebase = SysTick.

### Connectivity
- **SPI1**: Mode = **Full-Duplex Master**, Hardware NSS = **Disabled** → PA5/PA6/PA7.
  - Parameters: Data Size 8-bit, MSB First, **CPOL = High, CPHA = 2 Edge** (mode 3),
    Baud Rate Prescaler so SCLK **≤ 10 MHz** (e.g. /16 = 5 MHz to start).
- **USART2**: Mode = **Asynchronous** → PA2 (TX) / PA3 (RX). 115200 8N1.
- **SDMMC1**: Mode = **SD 4 bits Wide bus** → PC8/PC9/PC10/PC11 (D0–D3), PC12 (CK), PD2 (CMD).
- **USB**: Mode = **Device (FS)** → PA11 (DM) / PA12 (DP).

### Analog
- **ADC1**: enable **IN13** (PC4) and **IN14** (PC5). Resolution 12-bit,
  Sampling time long (247.5 cyc). Scan/continuous off (driver triggers reads).

### Timers
- **TIM1**: Channel1/2/3 = **PWM Generation CHx** → PA8/PA9/PA10.
  Prescaler **79**, Counter Period (ARR) **999** (1 kHz, 0–1000 duty).
- **TIM6**: **Activated** (basic timer). Prescaler 0, default ARR (driver sets
  it). This is the buzzer software-PWM timebase. In **NVIC Settings** for TIM6,
  tick **"TIM6 global interrupt"**.
  > The L452 has **no TIM17**, and **PB9 has no timer channel at all** (its AFs
  > are IR_OUT/I2C1_SDA/SPI2_NSS/CAN1_TX/SDMMC1_D5/SAI1_FS_A only). So the buzzer
  > is driven as a GPIO toggled from the TIM6 ISR (see `indication.c`). The OZONE
  > doc's "PB9 = TIM17_CH1" is an error.

### Middleware and Software Packs
- **FATFS**: Mode = **SD Card** (sits on SDMMC1). Needed for logging.
- **USB_DEVICE**: Class = **Communication Device Class (Virtual Port Com)**.

### GPIO — set each pin's mode + **User Label** (right-click pin → Enter User Label)
**Outputs, init High** (so no sensor is selected at boot):

| Pin  | Mode | User Label |
|---|---|---|
| PB0  | GPIO_Output High| `CS_H3LIS` |
| PB1  | GPIO_Output High| `CS_LIS3DH` |
| PB2  | GPIO_Output High| `CS_MS5611_1` |
| PB12 | GPIO_Output High| `CS_MS5611_2` |

**Outputs, init Low** (pyro safe + LEDs):

| Pin  | Mode | User Label |
|---|---|---|
| PB10 | GPIO_Output Low| `PYRO1_GATE` |
| PB11 | GPIO_Output Low| `PYRO2_GATE` |
| PB15 | GPIO_Output Low| `PYRO_ARM` |
| PB13 | GPIO_Output Low| `PYRO1_CONT_LED`  |
| PB14 | GPIO_Output Low| `PYRO2_CONT_LED`  |
| PB6  | GPIO_Output Low| `LED_HEARTBEAT` |
| PB7  | GPIO_Output Low| `LED_ERROR` |
| PB9  | GPIO_Output Low| `BUZZER` |

**Inputs:**

| Pin  | Mode | User Label | Note |
|---|---|---|---|
| PC0  | GPIO_Input  | `INT1_H3LIS` | accel interrupt |
| PC1  | GPIO_Input  | `INT1_LIS3DH` | |
| PC2  | GPIO_Input  | `INT2_LIS3DH` | |
| PC3  | GPIO_Input  | `SD_CD` | card detect, active-low |
| PB8  | GPIO_Input  | `PG_BUCKBOOST`  | TPS63060 power-good |
| PC6  | GPIO_Input  | `PYRO1_CONT` | **not ADC on L452** — digital go/no-go |
| PC7  | GPIO_Input  | `PYRO2_CONT` | **not ADC on L452** — digital go/no-go |

## C. Clock Configuration tab
- HSE input = **8 MHz**. Target **HCLK = 80 MHz** (type 80, let CubeMX resolve:
  PLL M=1, N=20, R=2). System Clock Mux = PLLCLK. APB1/APB2 prescaler = /1.
- **Clock48 source = HSI48** (feeds both **USB** and **SDMMC1**). Enable HSI48 + CRS.
- Resolve any red conflict by setting the Clock48 mux to HSI48.

## D. Project Manager tab
- **Project**: Toolchain/IDE = **STM32CubeIDE**. Project name `ozone-fw`,
  location = this `firmware/` folder.
- **Code Generator**: tick *Copy only necessary library files* and
  *Generate peripheral init as a pair of .c/.h files per peripheral*.

## E. Generate
- **GENERATE CODE** (top-right). Then in CubeIDE: File → Import → Existing
  Projects into Workspace → select the generated folder.
- Build (hammer). Should be 0 errors before adding `app/`.

## F. Add the app layer
Follow `app/INTEGRATION.md` (include path, `main.c` USER CODE hooks, float-printf).

## G. Flash
ST-Link → SWD header **J4** (pin1 +3V3, 2 SWDIO/PA13, 3 SWCLK/PA14, 4 GND, 5 NRST).
Run → Debug As → STM32 C/C++ Application. Heartbeat LED (PB6) blinks when alive.

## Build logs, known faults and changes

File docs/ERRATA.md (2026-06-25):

# Project OZONE — Hardware Errata & Future-Revision Changes

Issues found in **board rev 1.0** that are worked around in firmware on the
current (already-fabricated) board, and should be **fixed in hardware on the
next revision (rev 1.1 / v2.0)**.

Status legend: 🟢 firmware workaround in place on rev 1.0 · 🔧 fix in next rev.

---

## ERR-001 — Buzzer pin PB9 has no timer (no hardware PWM)
**Severity:** low (cosmetic/recovery aid, not flight-critical)

- **Problem:** §16 / §10.3 of the technical doc assign the buzzer to
  `PB9 / TIM17_CH1`. The **STM32L452 has no TIM17**, and **PB9 has no timer
  channel of any kind** (its alternate functions are only IR_OUT, I2C1_SDA,
  SPI2_NSS, CAN1_TX, SDMMC1_D5, SAI1_FS_A — verified in the STM32L452
  datasheet AF table). So PB9 cannot produce hardware PWM.
- 🟢 **Rev 1.0 workaround:** drive PB9 as GPIO, generate the tone in software
  from the **TIM6** update interrupt (`firmware/app/Src/indication.c`,
  `buzzer_tone()` / `HAL_TIM_PeriodElapsedCallback`). Works fine for a piezo;
  costs a few thousand cheap ISRs/sec.
- 🔧 **Rev 1.1 fix:** route the buzzer FET gate to a pin **with a timer channel**
  so it's true hardware PWM and frees the CPU. Good free candidates:
  - **PA15 → TIM2_CH1** (AF1)
  - **PB4 → TIM3_CH1** (AF2)
  - **PB5 → TIM3_CH2** (AF2)

  Then revert `indication.c` to a one-line `__HAL_TIM_SET_COMPARE` PWM driver.

---

## ERR-002 — Pyro continuity pins PC6/PC7 are not ADC-capable
**Severity:** medium (limits continuity to go/no-go, not analog readback)

- **Problem:** §16 lists `PC6 = PYRO1_CONT` and `PC7 = PYRO2_CONT` as "ADC/GPIO",
  and §7.3 / §13/§14.7 describe reading a **continuity ADC voltage**. But on the
  STM32L452, ADC1 has **no channel on PC6/PC7** (ADC1 reaches PC0–PC5, PA0–PA7,
  PB0/PB1 only). So an analog continuity *voltage* cannot be measured on these
  pins.
- 🟢 **Rev 1.0 workaround:** read PC6/PC7 as **GPIO digital** present/absent
  (`firmware/app/Src/pyro.c`, `pyro_continuity()`), using the divider node
  crossing the logic threshold. Adequate for a go/no-go continuity check before
  arming; not a measured resistance/voltage.
- 🔧 **Rev 1.1 fix:** route the two continuity divider nodes to **ADC-capable
  free pins** for true analog continuity (so the BT telemetry can report an
  actual voltage per §13.1/§14.7):
  - **PA4 → ADC1_IN9**
  - **PA0 → ADC1_IN5**  (or PA1 → ADC1_IN6)

  Then read them with the existing `adc_read_raw()` path in `adc_sense.c`.

---

## ERR-003 — Documentation correction (no silicon impact)
- The technical doc references **TIM17** (§10.3, §16) which does not exist on the
  STM32L452. Update those rows to reflect the buzzer being GPIO/TIM6 on rev 1.0
  (per ERR-001). The board itself is unaffected; this is a doc-only fix.

---

## Carried-forward / already-resolved (for reference)
- **5.1 V Zener** on the reverse-polarity P-FET gate (replacing the original
  8.2 V) — already corrected in rev 1.0 (doc §5.2). No further action.

---

## Suggested rev 1.1 pin reassignment summary
| Function | rev 1.0 pin | rev 1.1 pin | Why |
|---|---|---|-----|
| Buzzer | PB9 (GPIO)  | PA15 / PB4  | gain hardware-PWM timer channel |
| Pyro1 continuity| PC6 (GPIO)  | PA4 (IN9) | gain ADC for analog continuity  |
| Pyro2 continuity| PC7 (GPIO)  | PA0 (IN5) | gain ADC for analog continuity  |

Freed by the moves: PB9, PC6, PC7 become spare GPIO. Confirm the chosen pins are
not otherwise allocated before routing, and re-run the CubeMX pinout + update
`firmware/app/Inc/ozone_hal.h` labels to match.

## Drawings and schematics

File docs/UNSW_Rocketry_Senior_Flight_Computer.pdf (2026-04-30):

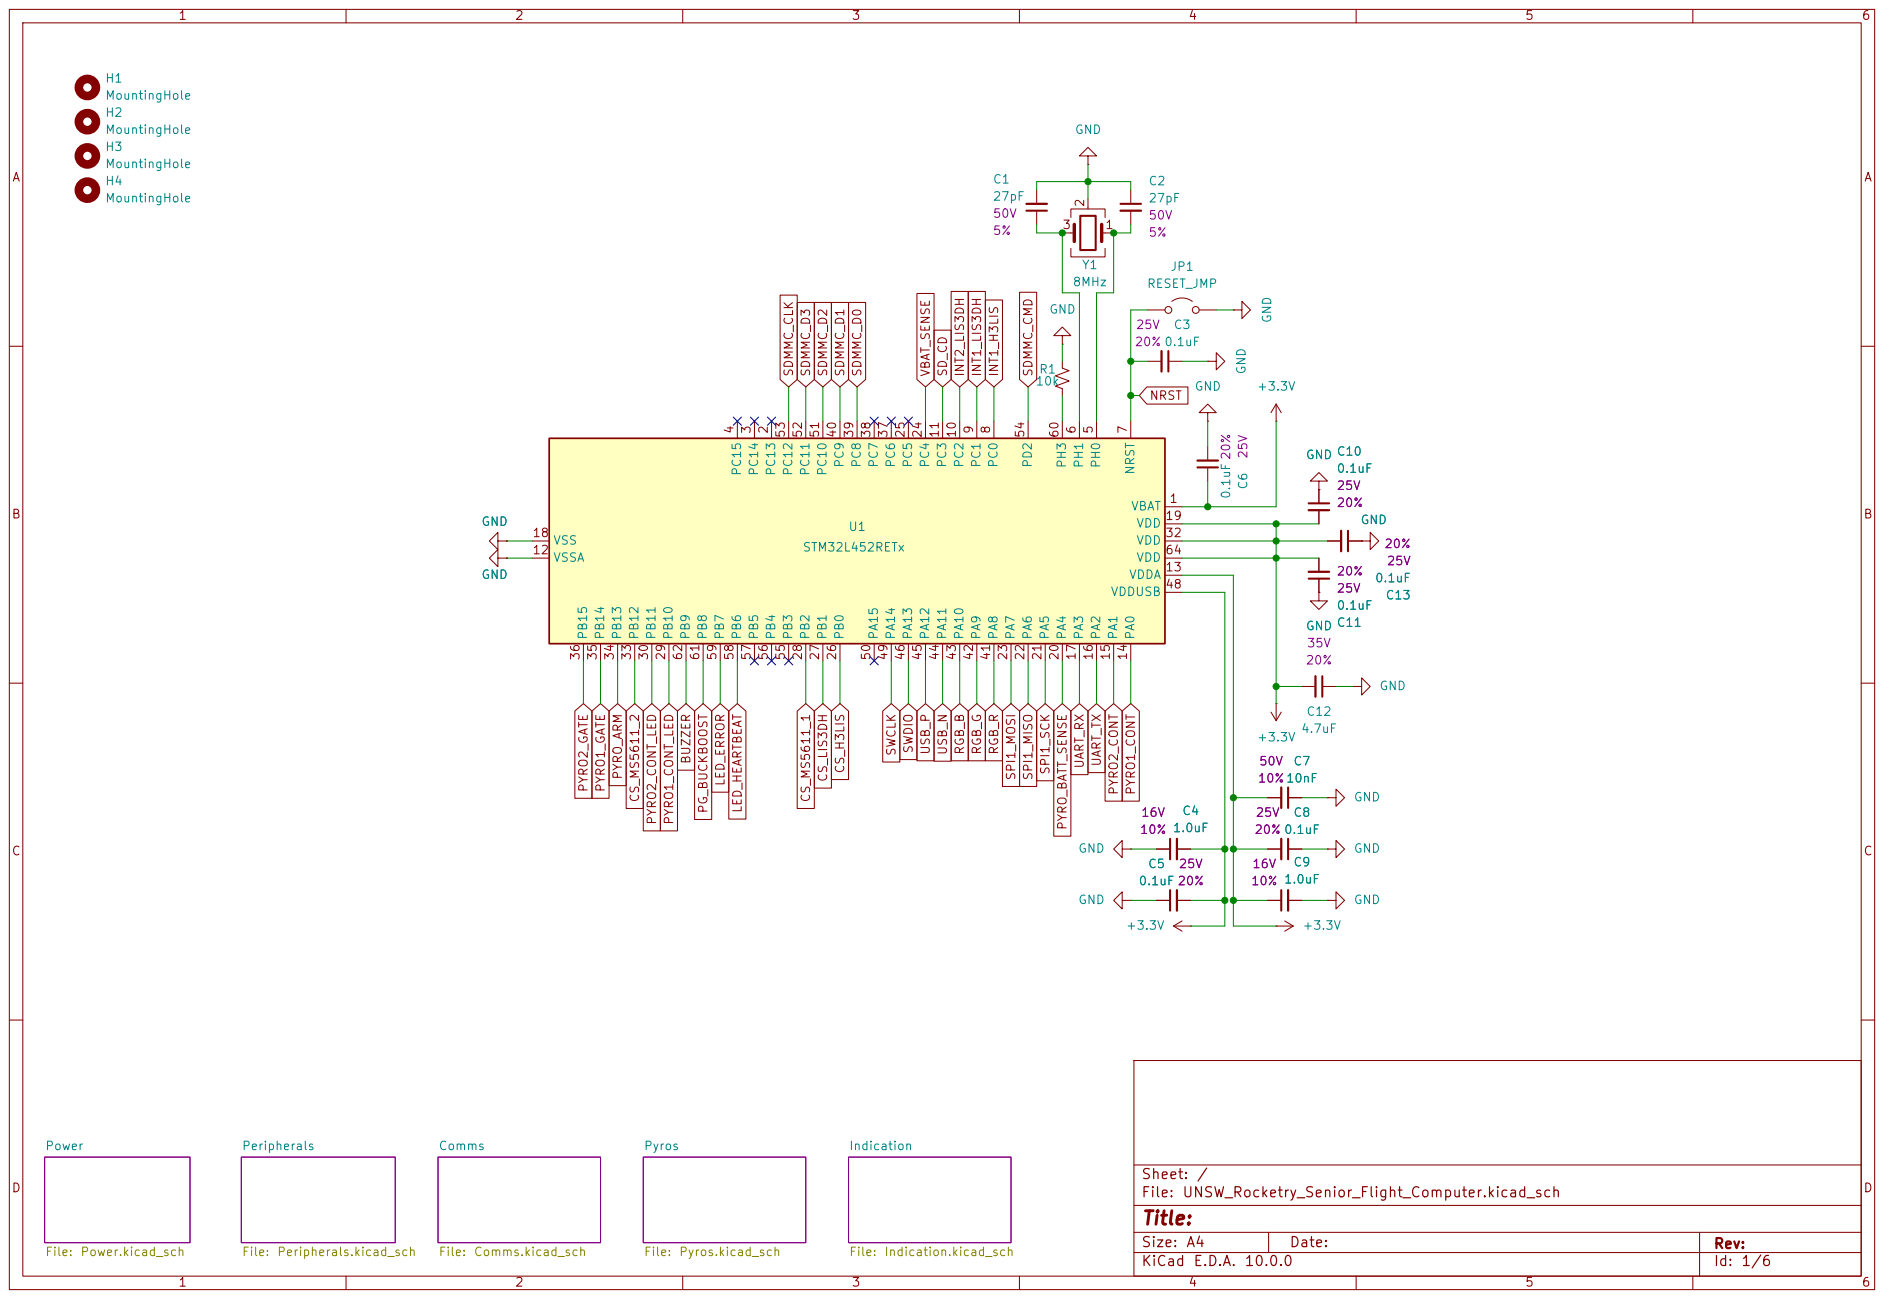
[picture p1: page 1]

Size: A4 | Rev:
KiCad E.D.A. 10.0.0 | Id: 1/6

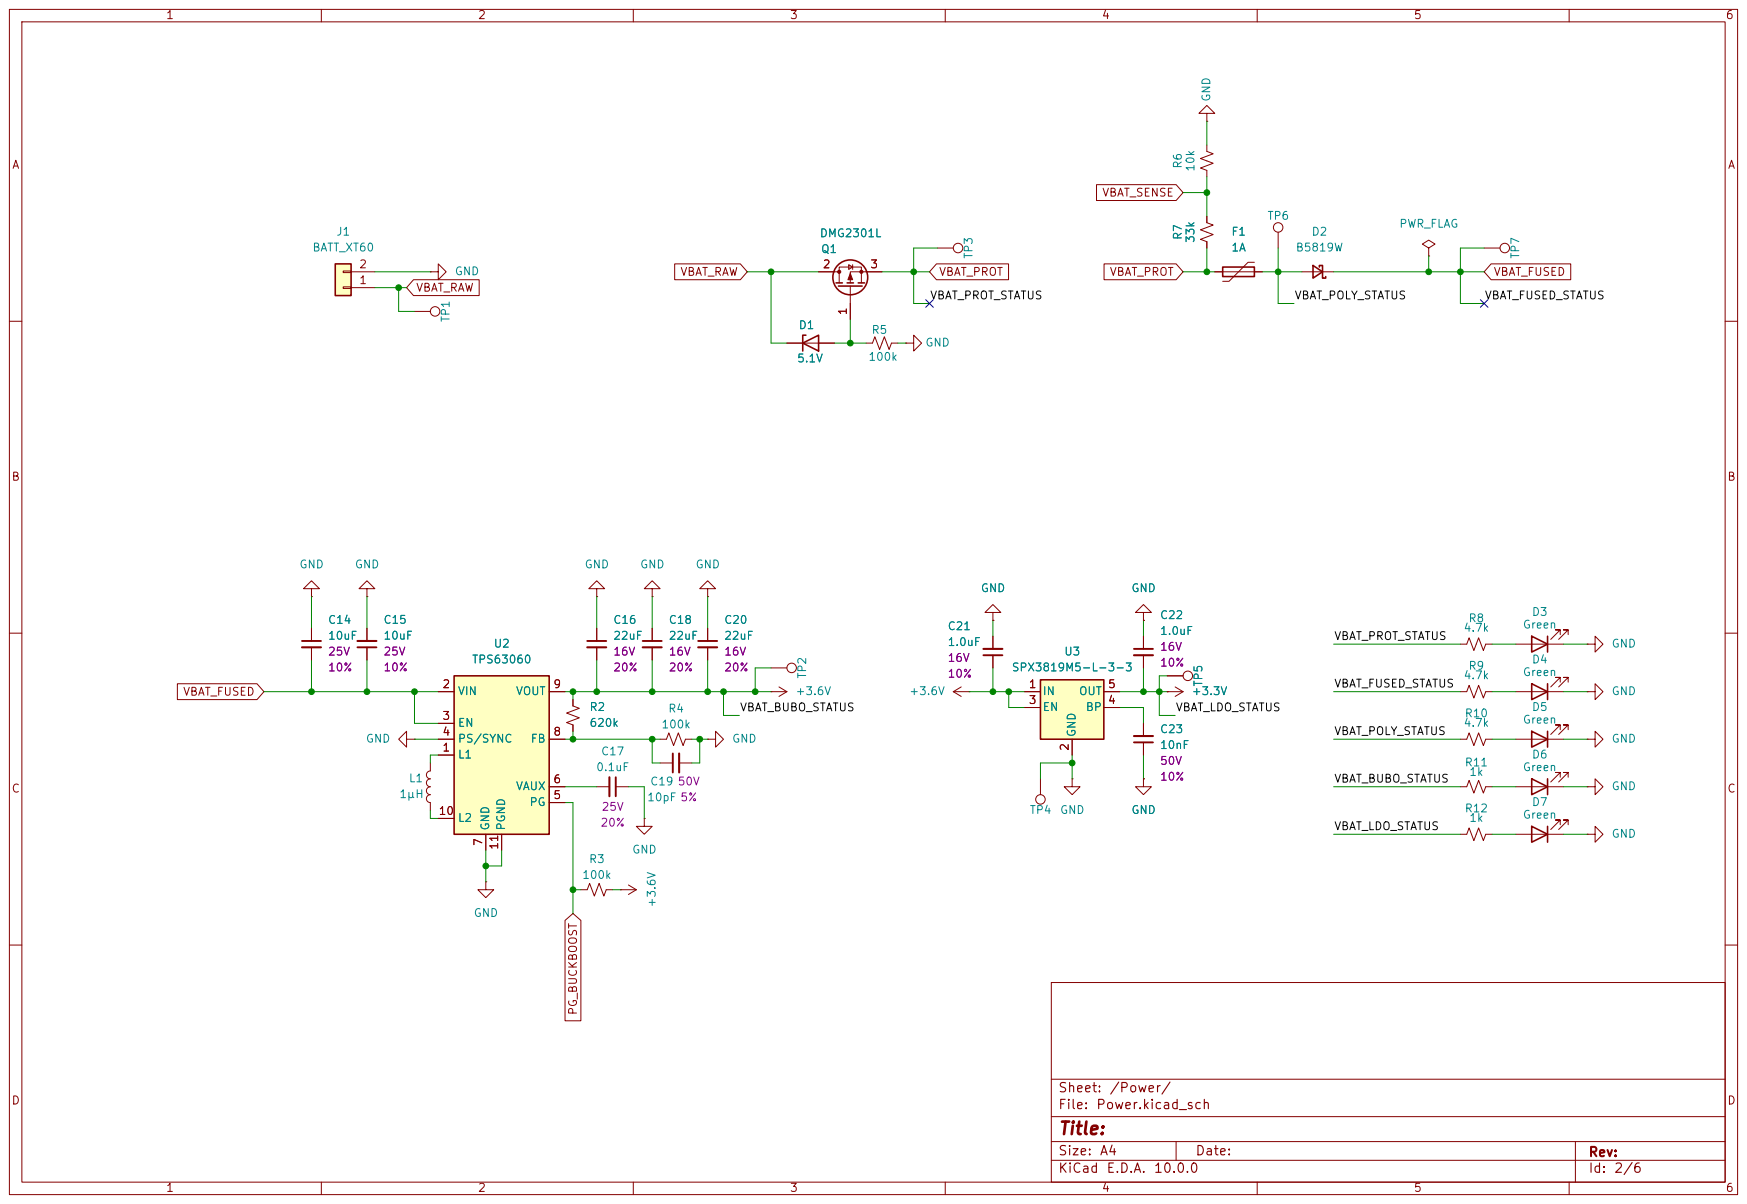
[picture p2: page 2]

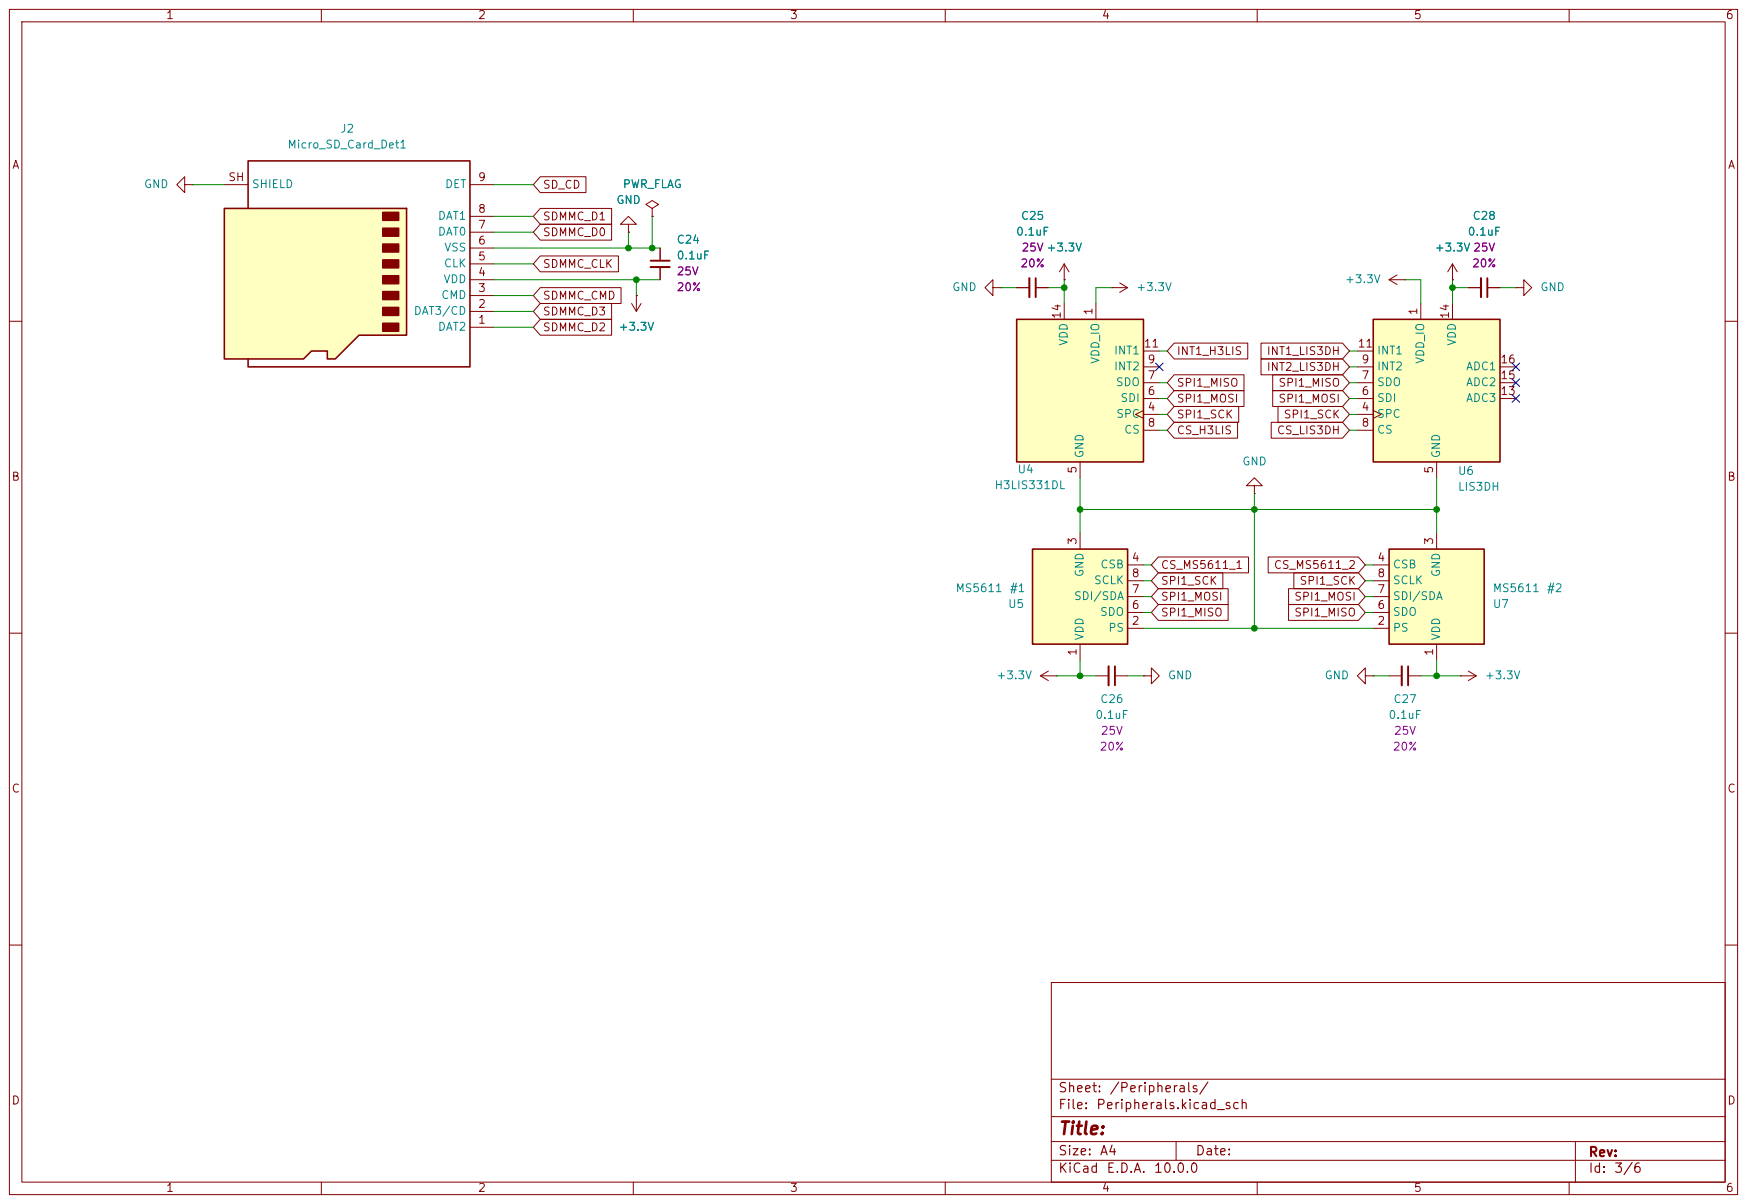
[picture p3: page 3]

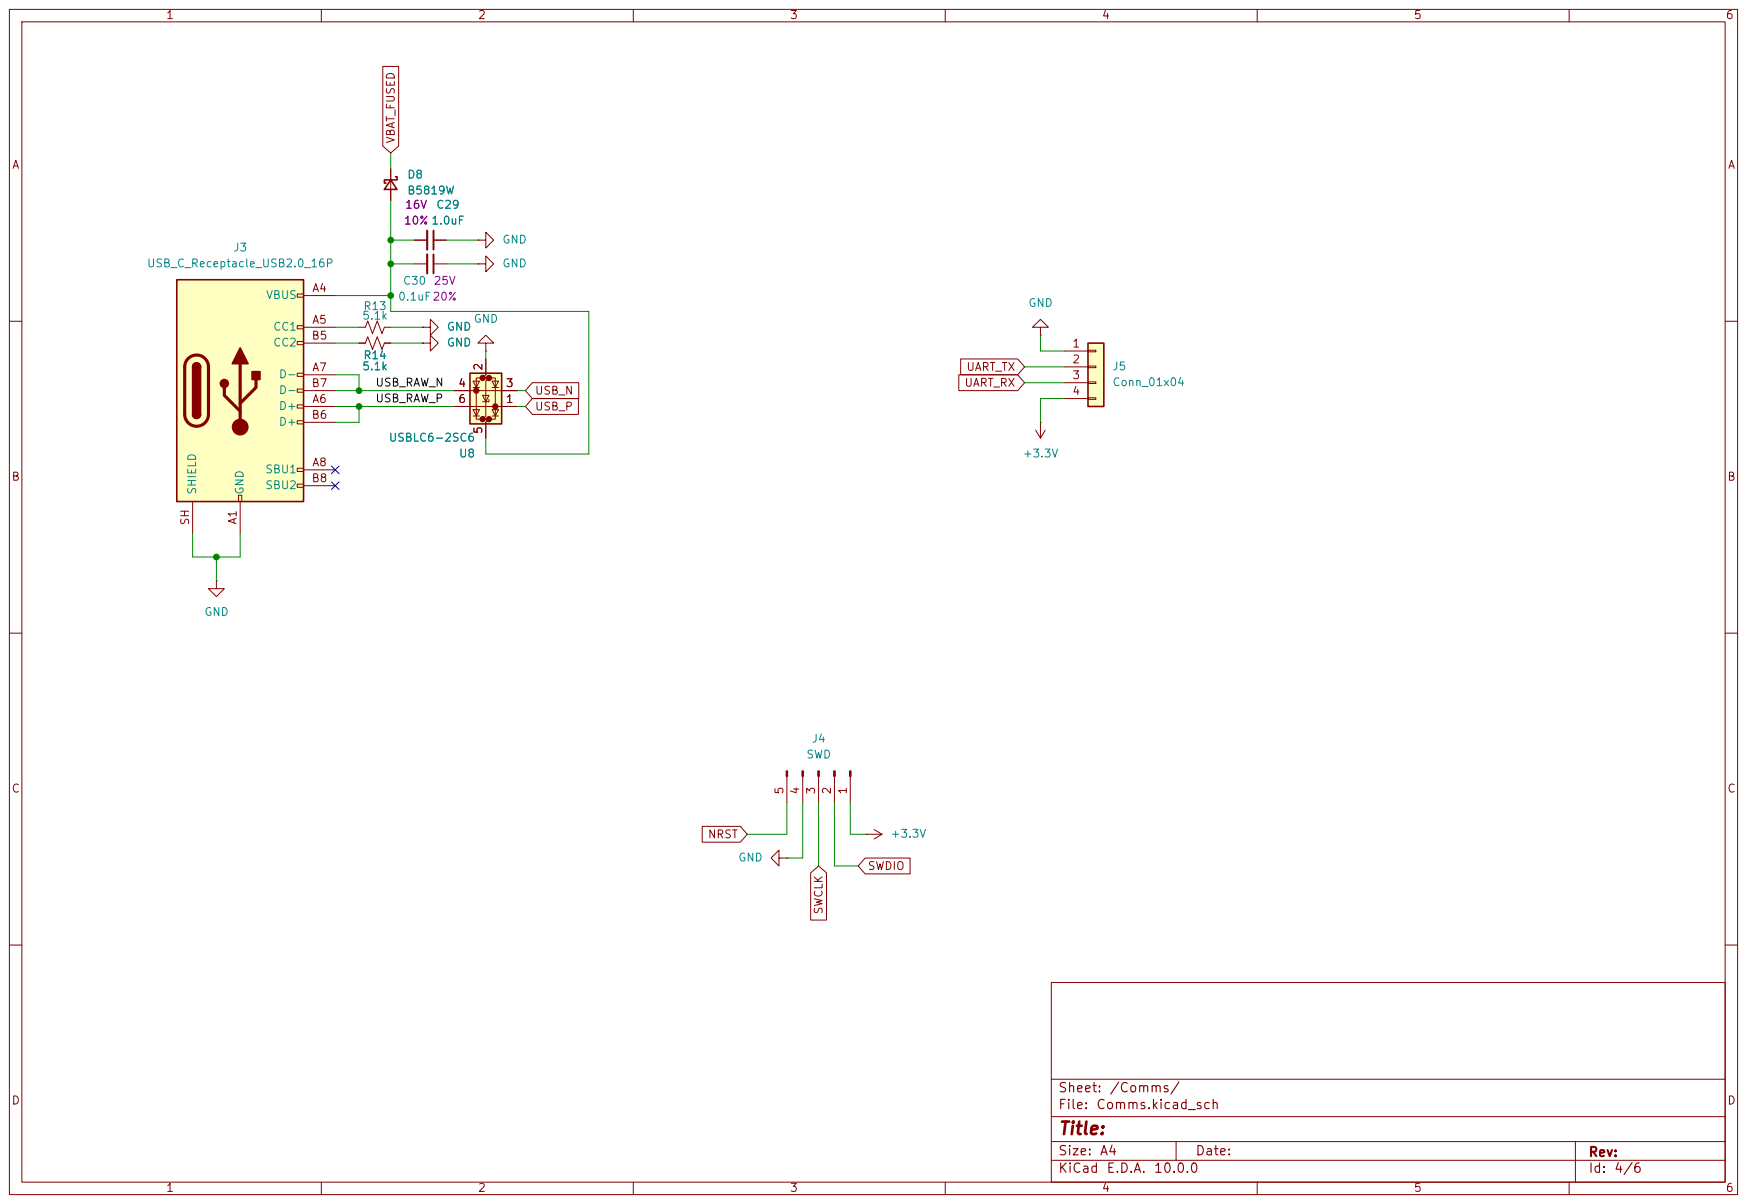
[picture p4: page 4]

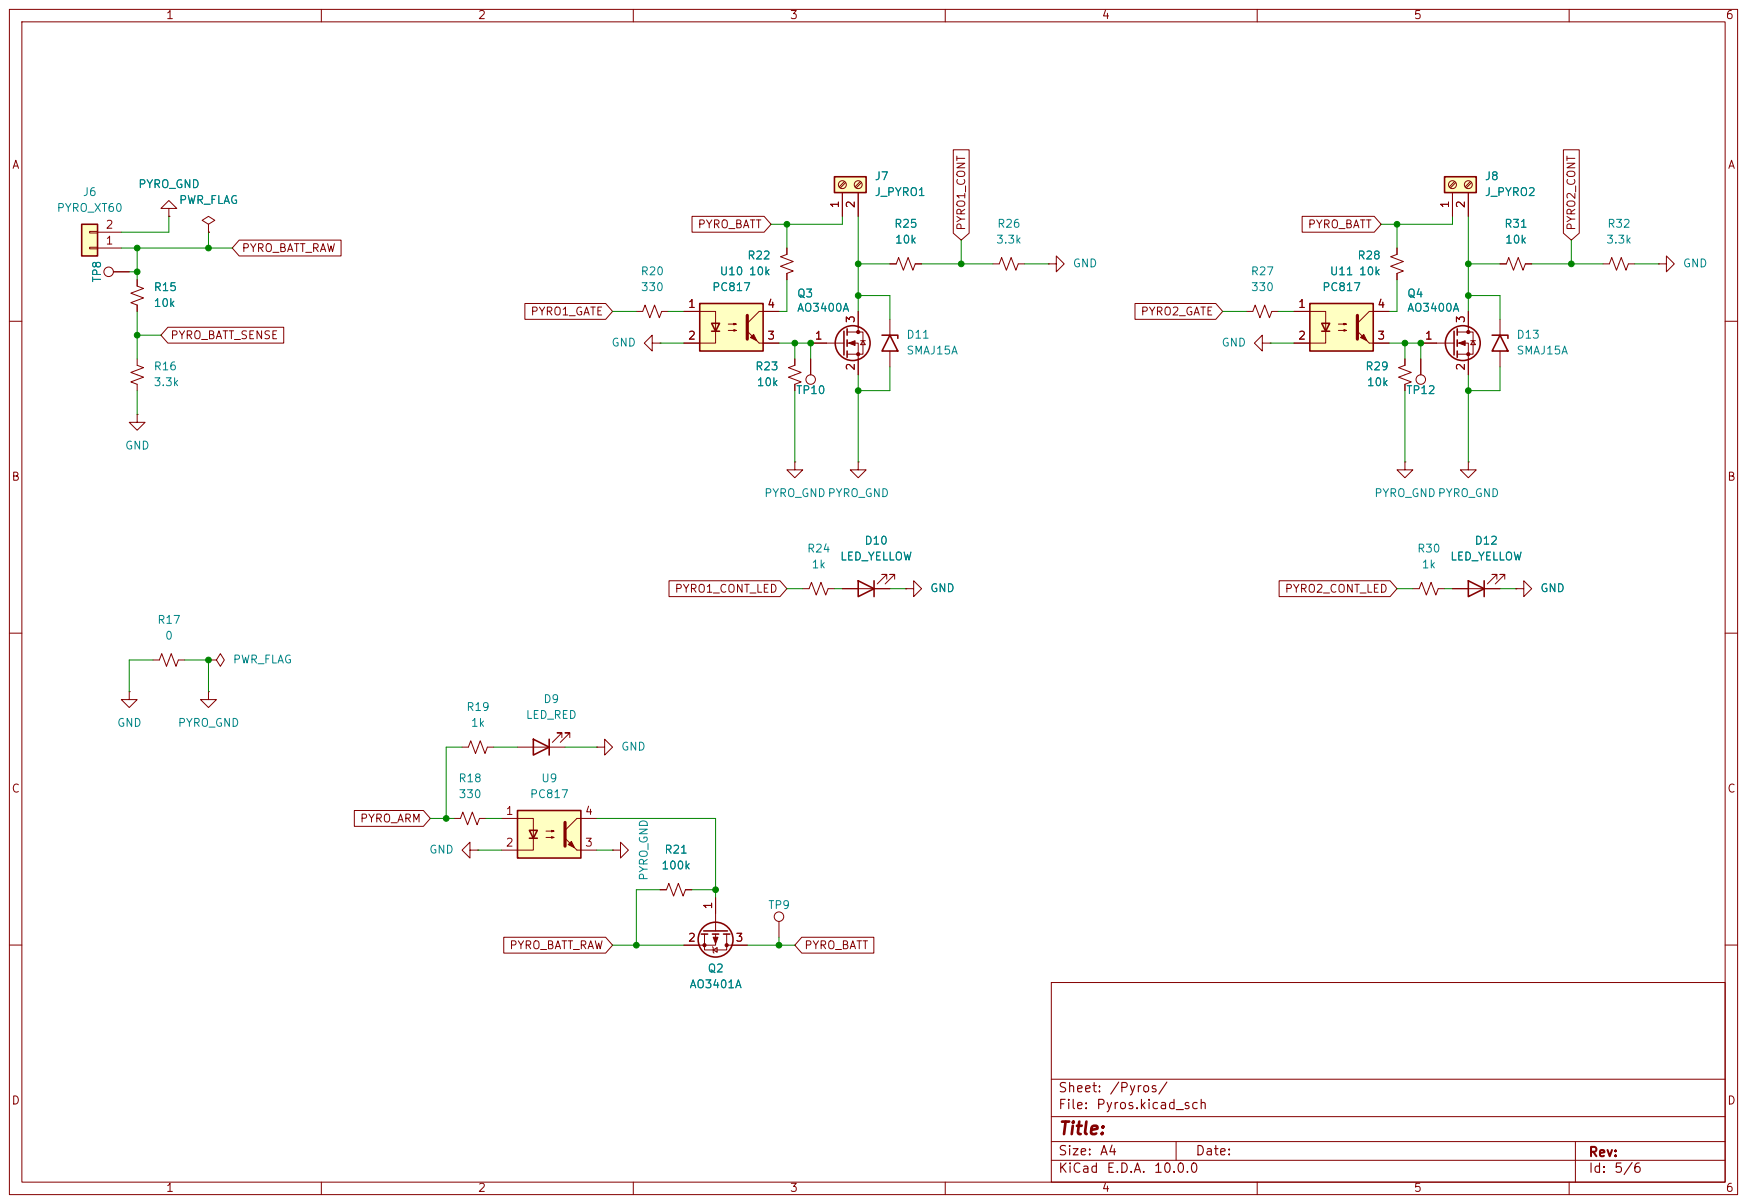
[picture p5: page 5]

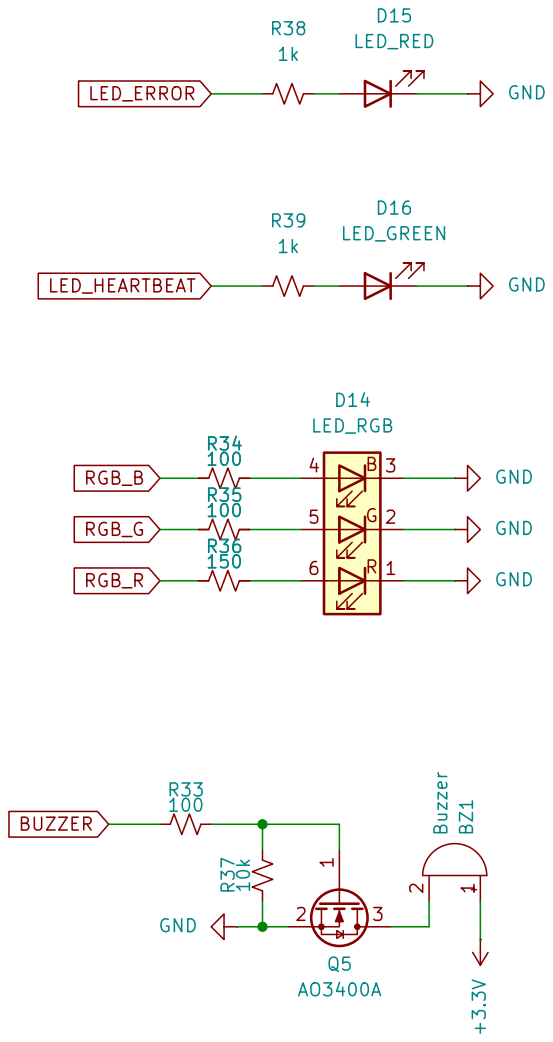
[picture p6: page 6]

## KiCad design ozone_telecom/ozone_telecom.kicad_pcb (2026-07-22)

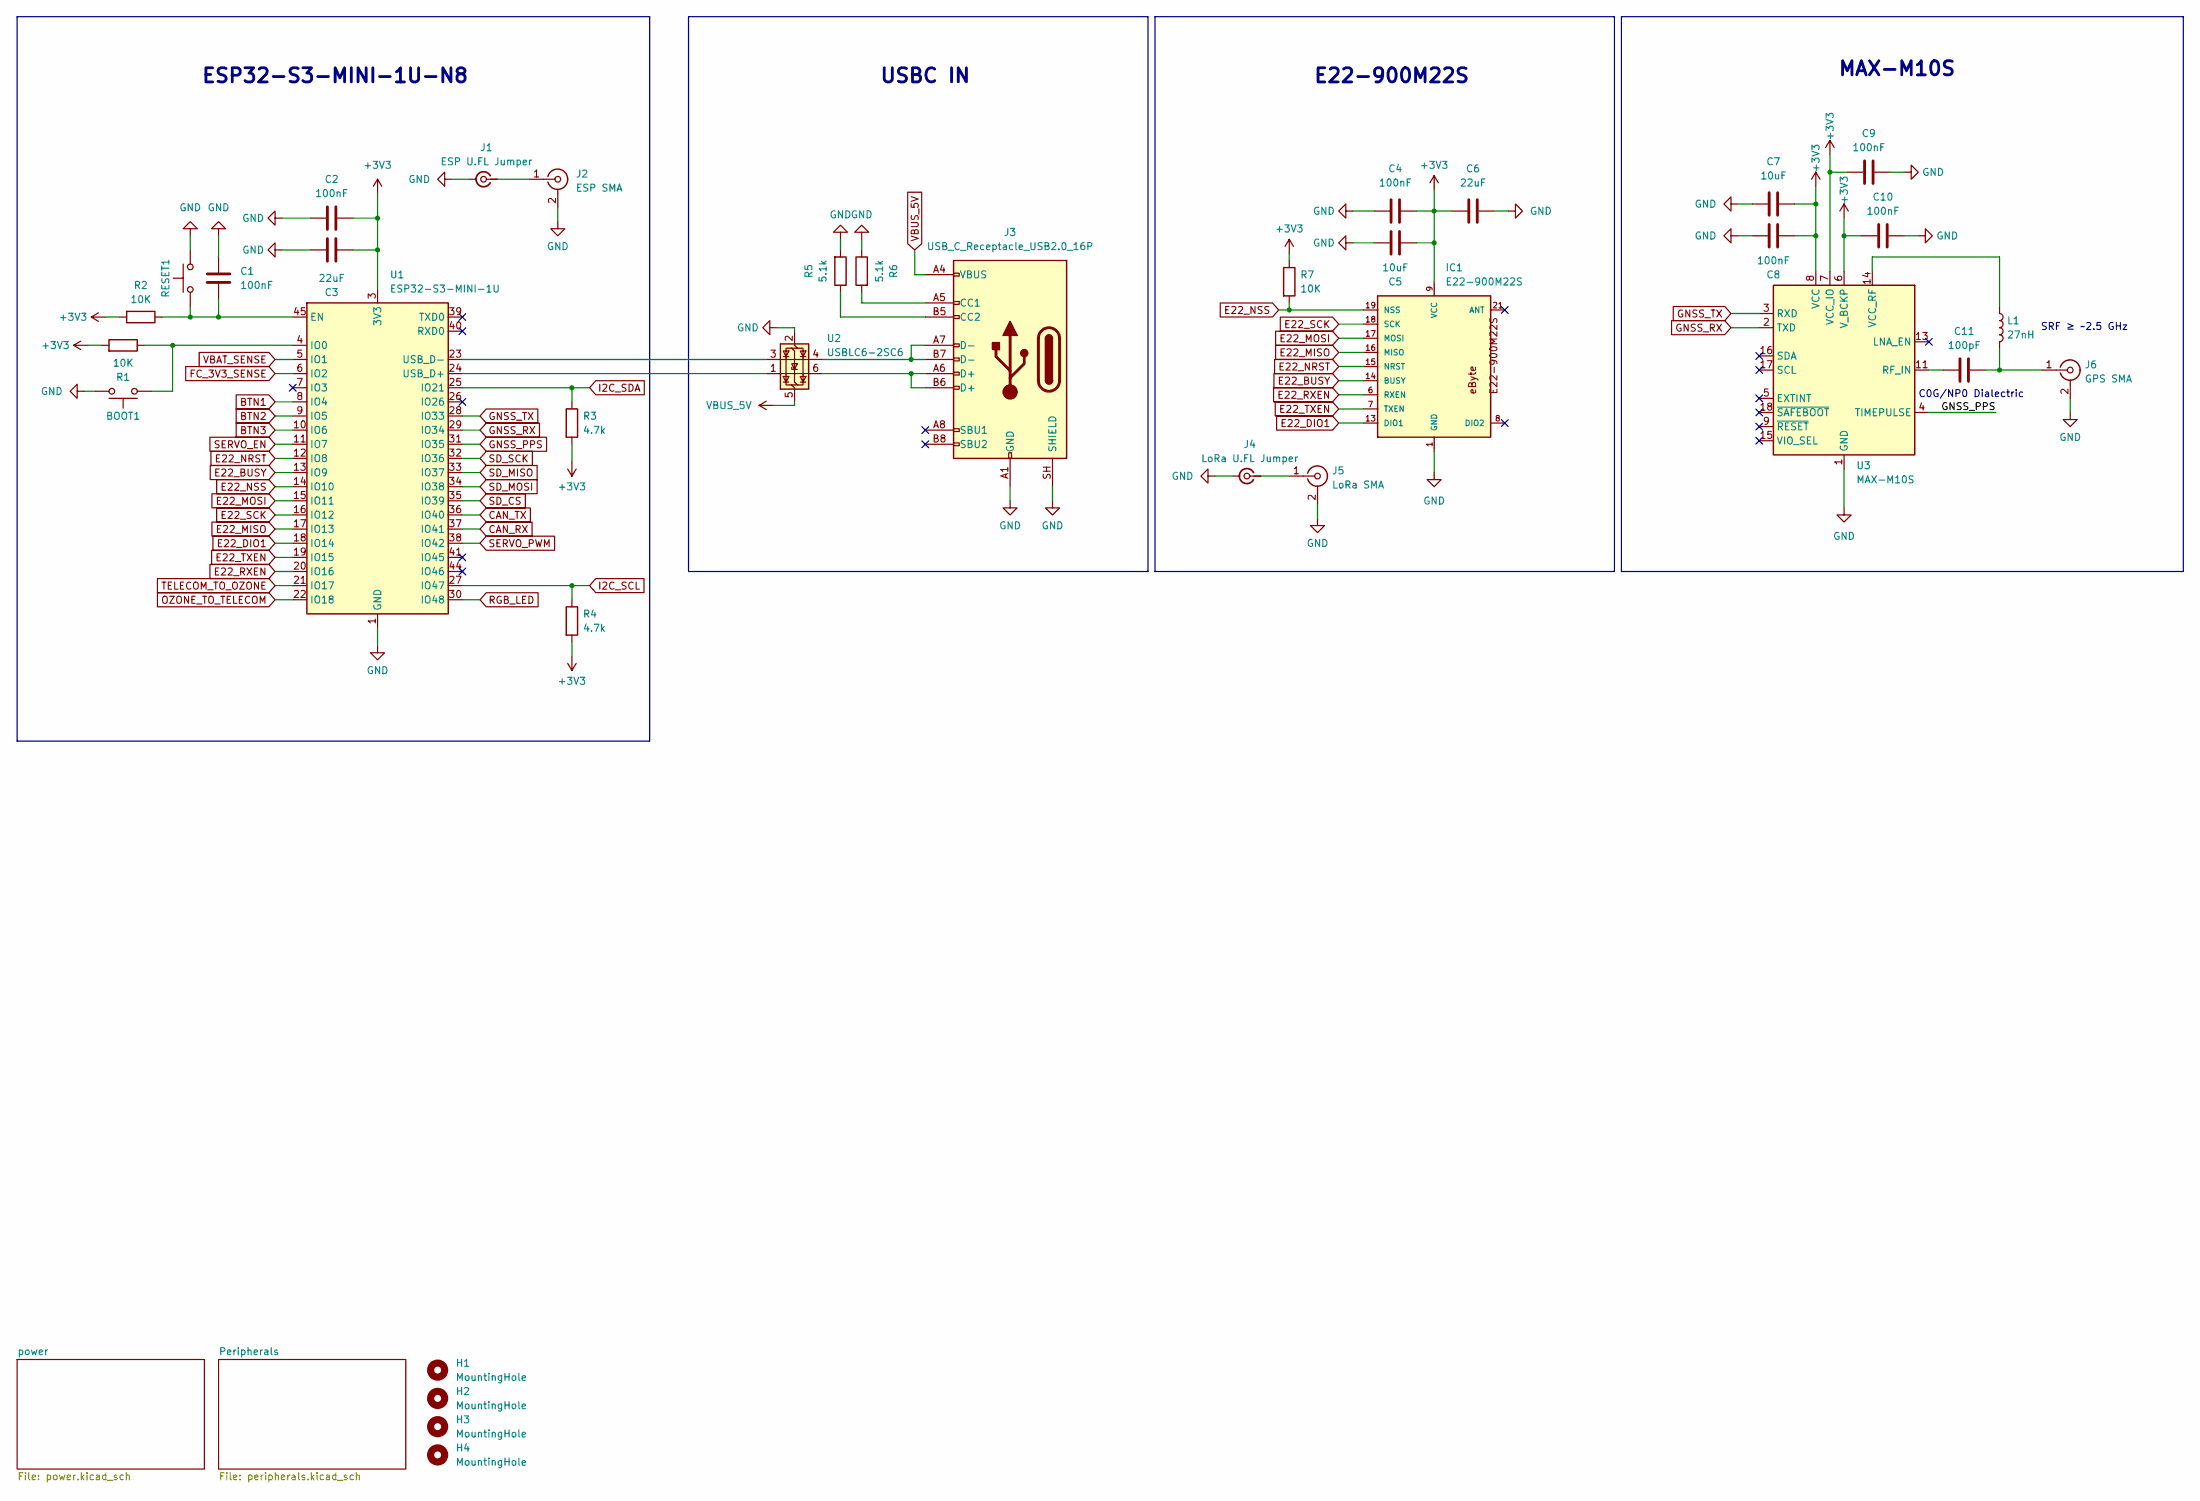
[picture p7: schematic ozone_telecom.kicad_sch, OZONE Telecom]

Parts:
BOOT1: SMD_4.6x2.8mm_h1.9mm; Push_SMD_4.6x2.8mm_h1.9mm
C1: 100nF; C_0603_1608Metric
C2, C4, C8, C9, C10: 100nF; C_0805_2012Metric
C3, C6: 22uF; C_0805_2012Metric
C5, C7: 10uF; C_0805_2012Metric
C11: 100pF; C_0603_1608Metric
H1, H2, H3, H4: MountingHole; MountingHole_3.2mm_M3_DIN965_Pad
IC1: E22-900M22S
J1: ESP U.FL Jumper; U.FL_Hirose_U.FL-R-SMT-1_Vertical
J2: ESP SMA; SMA_Amphenol_132289_EdgeMount
J3: USB_C_Receptacle_USB2.0_16P; USB_C_Receptacle_GCT_USB4085
J4: LoRa U.FL Jumper; U.FL_Hirose_U.FL-R-SMT-1_Vertical
J5: LoRa SMA; SMA_Amphenol_132289_EdgeMount
J6: GPS SMA; SMA_Amphenol_132289_EdgeMount
L1: 27nH; L_0603_1608Metric
R1, R2, R7: 10K; R_0603_1608Metric
R3, R4: 4.7k; R_0603_1608Metric
R5, R6: 5.1k; R_0603_1608Metric
RESET1: SMD_4.6x2.8mm_h1.9mm; Push_SMD_4.6x2.8mm_h1.9mm
U1: ESP32-S3-MINI-1U; ESP32-S2-MINI-1U
U2: USBLC6-2SC6; SOT-23-6
U3: MAX-M10S; ublox_MAX

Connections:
+3V3: C2.1, C3.1, C4.2, C5.2, C6.1, C7.1, C8.1, C9.2, C10.2, IC1.9 (VCC), R1.2, R2.2, R3.2, R4.2, R7.1, U1.3 (3V3), U3.6 (V_BCKP), U3.7 (VCC_IO), U3.8 (VCC); also elsewhere on the board
BTN1: U1.8 (IO4); also elsewhere on the board
BTN2: U1.9 (IO5); also elsewhere on the board
BTN3: U1.10 (IO6); also elsewhere on the board
CAN_RX: U1.37 (IO41); also elsewhere on the board
CAN_TX: U1.36 (IO40); also elsewhere on the board
E22_BUSY: IC1.14 (BUSY), U1.13 (IO9)
E22_DIO1: IC1.13 (DIO1), U1.18 (IO14)
E22_MISO: IC1.16 (MISO), U1.17 (IO13)
E22_MOSI: IC1.17 (MOSI), U1.15 (IO11)
E22_NRST: IC1.15 (NRST), U1.12 (IO8)
E22_NSS: IC1.19 (NSS), R7.2, U1.14 (IO10)
E22_RXEN: IC1.6 (RXEN), U1.20 (IO16)
E22_SCK: IC1.18 (SCK), U1.16 (IO12)
E22_TXEN: IC1.7 (TXEN), U1.19 (IO15)
FC_3V3_SENSE: U1.6 (IO2); also elsewhere on the board
GND: BOOT1.2, C1.1, C2.2, C3.2, C4.1, C5.1, C6.2, C7.2, C8.2, C9.1, C10.1, IC1.1 (GND), IC1.2 (GND), IC1.3 (GND), IC1.4 (GND), IC1.5 (GND), IC1.10 (GND), IC1.11 (GND), IC1.12 (GND), IC1.20 (GND), IC1.22 (GND), J1.2 (Ext), J2.2 (Ext), J3.A1 (GND), J3.A12 (GND), J3.B1 (GND), J3.B12 (GND), J3.SH (SHIELD), J4.2 (Ext), J5.2 (Ext), J6.2 (Ext), R5.2, R6.1, RESET1.1, U1.1 (GND), U1.2 (GND), U1.42 (GND), U1.43 (GND), U1.46 (GND), U1.47 (GND), U1.48 (GND), U1.49 (GND), U1.50 (GND), U1.51 (GND), U1.52 (GND), U1.53 (GND), U1.54 (GND), U1.55 (GND), U1.56 (GND), U1.57 (GND), U1.58 (GND), U1.59 (GND), U1.60 (GND), U1.61 (GND), U1.62 (GND), U1.63 (GND), U1.64 (GND), U1.65 (GND), U2.2 (GND), U3.1 (GND), U3.10 (GND), U3.12 (GND); also elsewhere on the board
GNSS_PPS: U1.31 (IO35), U3.4 (TIMEPULSE)
GNSS_RX: U1.29 (IO34), U3.2 (TXD)
GNSS_TX: U1.28 (IO33), U3.3 (RXD)
I2C_SCL: R4.1, U1.27 (IO47); also elsewhere on the board
I2C_SDA: R3.1, U1.25 (IO21); also elsewhere on the board
unnamed: J1.1 (In), J2.1 (In)
unnamed: J3.A5 (CC1), R6.2
unnamed: J3.B5 (CC2), R5.1
unnamed: J3.A6 (D+), J3.B6 (D+), U2.6 (I/O1)
unnamed: J3.A7 (D-), J3.B7 (D-), U2.4 (I/O2)
unnamed: J4.1 (In), J5.1 (In)
unnamed: C11.1, J6.1 (In), L1.2
unnamed: C1.2, R2.1, RESET1.2, U1.45 (EN)
unnamed: BOOT1.1, R1.1, U1.4 (IO0)
unnamed: U1.24 (USB_D+), U2.1 (I/O1)
unnamed: U1.23 (USB_D-), U2.3 (I/O2)
unnamed: C11.2, U3.11 (RF_IN)
unnamed: L1.1, U3.14 (VCC_RF)
OZONE_TO_TELECOM: U1.22 (IO18); also elsewhere on the board
RGB_LED: U1.30 (IO48); also elsewhere on the board
SD_CS: U1.35 (IO39); also elsewhere on the board
SD_MISO: U1.33 (IO37); also elsewhere on the board
SD_MOSI: U1.34 (IO38); also elsewhere on the board
SD_SCK: U1.32 (IO36); also elsewhere on the board
SERVO_EN: U1.11 (IO7); also elsewhere on the board
SERVO_PWM: U1.38 (IO42); also elsewhere on the board
TELECOM_TO_OZONE: U1.21 (IO17); also elsewhere on the board
VBAT_SENSE: U1.5 (IO1); also elsewhere on the board
VBUS_5V: J3.A4 (VBUS), J3.A9 (VBUS), J3.B4 (VBUS), J3.B9 (VBUS), U2.5 (VBUS); also elsewhere on the board

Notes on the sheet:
SRF ≥ ~2.5 GHz
E22-900M22S
C0G/NP0 Dialectric
ESP32-S3-MINI-1U-N8
MAX-M10S
USBC IN

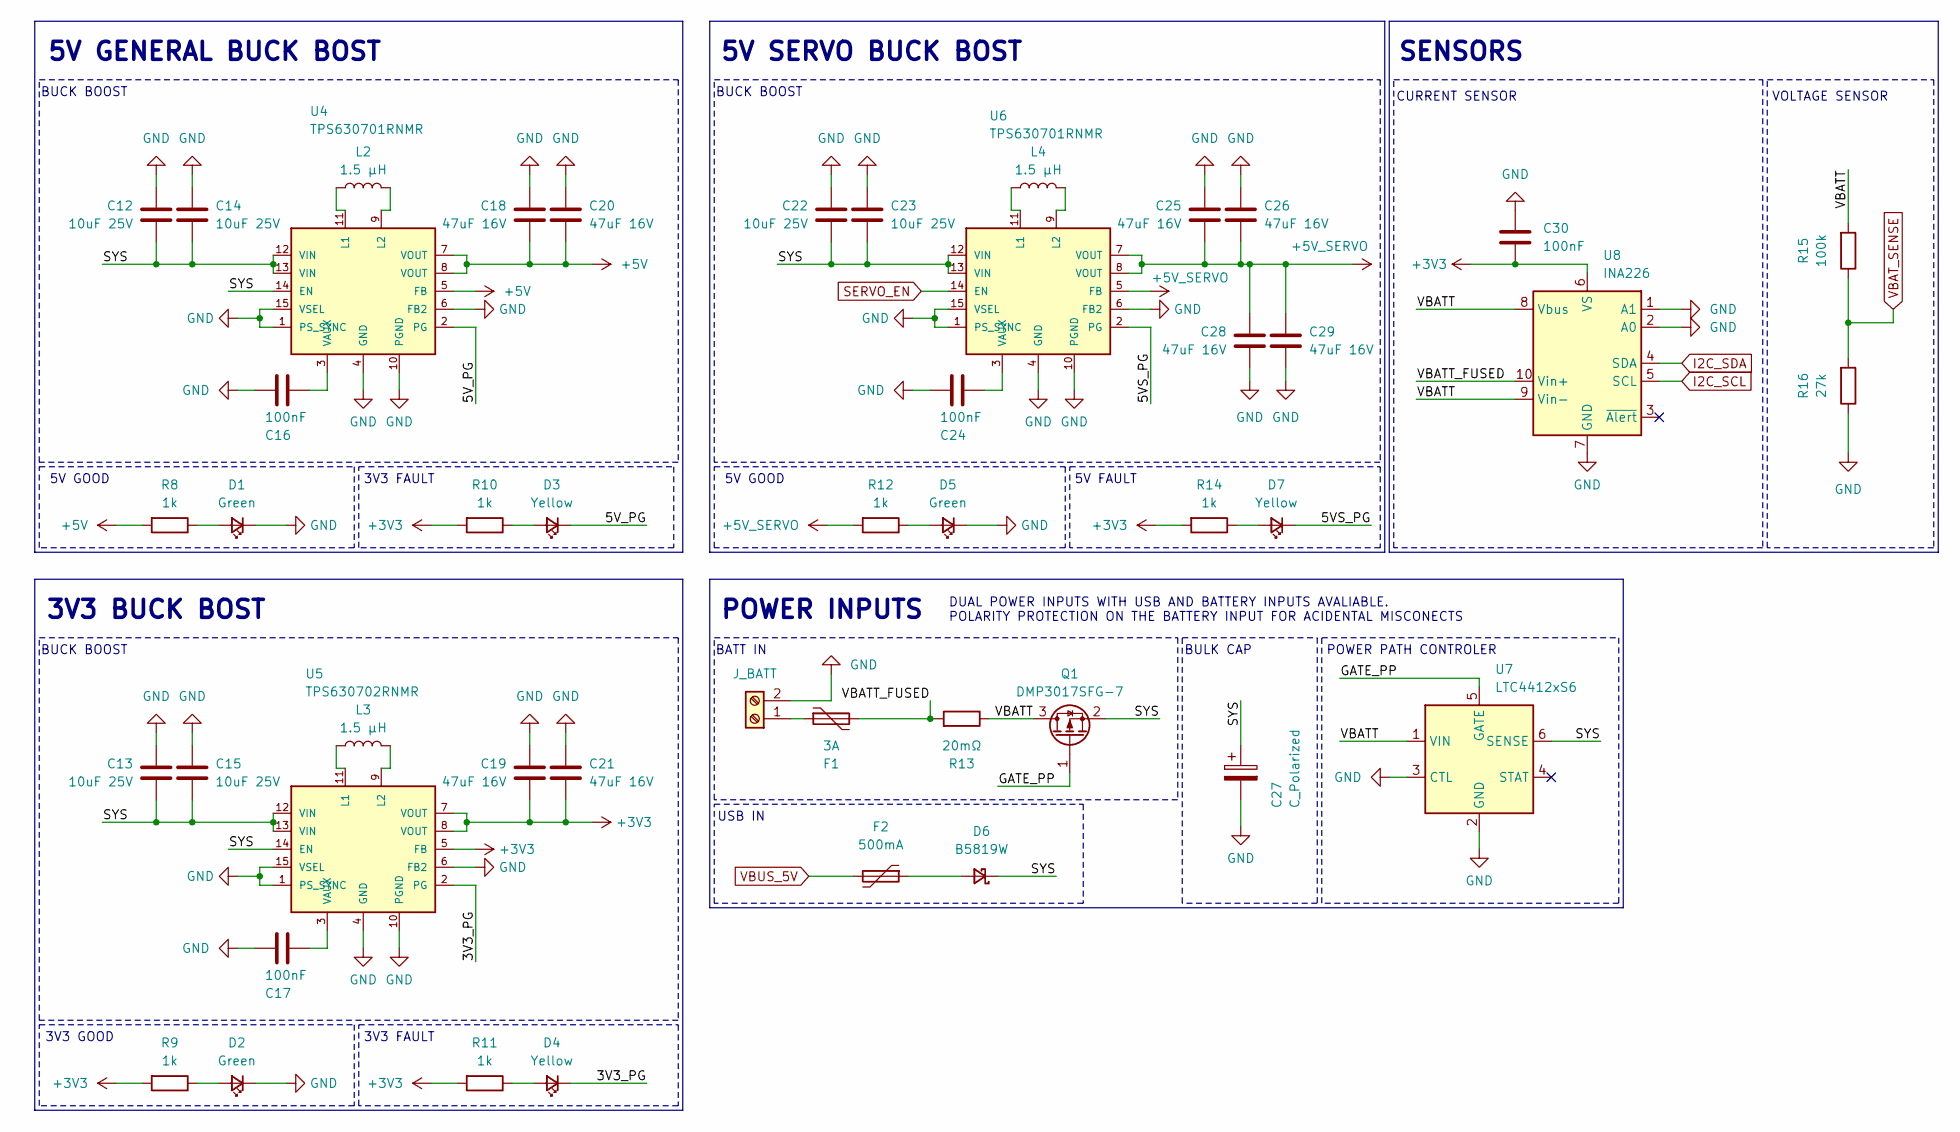
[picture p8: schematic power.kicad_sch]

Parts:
C12, C13, C14, C15, C22, C23: 10uF 25V; C_0805_2012Metric
C16, C17, C24, C30: 100nF; C_0805_2012Metric
C18, C19, C20, C21, C25, C26, C28, C29: 47uF 16V; C_0805_2012Metric
C27: C_Polarized; CP_Elec_6.3x5.4
D1, D2, D5: Green; LED_0603_1608Metric_Green
D3, D4, D7: Yellow; LED_0603_1608Metric_Yellow
D6: B5819W; D_SOD-123
F1: 3A; Fuse_1206_3216Metric
F2: 500mA; Fuse_1206_3216Metric
J7: J_BATT; TerminalBlock_Phoenix_PT-1,5-2-3.5-H_1x02_P3.50mm_Horizontal
L2, L3, L4: 1.5 µH; L_Coilcraft_XxL4020
Q1: DMP3017SFG-7; SOT-23
R8, R9, R10, R11, R12, R14: 1k; R_0603_1608Metric
R13: 20mΩ; R_2512_6332Metric
R15: 100k; R_0603_1608Metric
R16: 27k; R_0603_1608Metric
U4, U6: TPS630701RNMR; RNM0015A
U5: TPS630702RNMR; RNM0015A
U7: LTC4412xS6; TSOT-23-6
U8: INA226; TSSOP-10_3x3mm_P0.5mm

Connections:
+3V3: C19.2, C21.2, C30.2, R9.2, R10.2, R11.2, R14.2, U5.5 (FB), U5.7 (VOUT), U5.8 (VOUT), U8.6 (VS); also elsewhere on the board
+5V: C18.2, C20.2, R8.2, U4.5 (FB), U4.7 (VOUT), U4.8 (VOUT); also elsewhere on the board
+5V_SERVO: C25.2, C26.2, C28.1, C29.1, R12.2, U6.5 (FB), U6.7 (VOUT), U6.8 (VOUT); also elsewhere on the board
/power/3V3_PG: D4.1 (K), U5.2 (PG)
/power/5VS_PG: D7.1 (K), U6.2 (PG)
/power/5V_PG: D3.1 (K), U4.2 (PG)
/power/GATE_PP: Q1.1 (G), U7.5 (GATE)
/power/SYS: C12.2, C13.2, C14.2, C15.2, C22.2, C23.2, C27.1, D6.1 (K), Q1.2 (S), U4.12 (VIN), U4.13 (VIN), U4.14 (EN), U5.12 (VIN), U5.13 (VIN), U5.14 (EN), U6.12 (VIN), U6.13 (VIN), U7.6 (SENSE)
/power/VBATT: Q1.3 (D), R13.1, R15.2, U7.1 (VIN), U8.8 (Vbus), U8.9 (Vin-)
/power/VBATT_FUSED: F1.2, R13.2, U8.10 (Vin+)
GND: C12.1, C13.1, C14.1, C15.1, C16.2, C17.2, C18.1, C19.1, C20.1, C21.1, C22.1, C23.1, C24.2, C25.1, C26.1, C27.2, C28.2, C29.2, C30.1, D1.1 (K), D2.1 (K), D5.1 (K), J7.2, R16.1, U4.1 (PS_SYNC), U4.4 (GND), U4.6 (FB2), U4.10 (PGND), U4.15 (VSEL), U5.1 (PS_SYNC), U5.4 (GND), U5.6 (FB2), U5.10 (PGND), U5.15 (VSEL), U6.1 (PS_SYNC), U6.4 (GND), U6.6 (FB2), U6.10 (PGND), U6.15 (VSEL), U7.2 (GND), U7.3 (CTL), U8.1 (A1), U8.2 (A0), U8.7 (GND); also elsewhere on the board
I2C_SCL: U8.5 (SCL); also elsewhere on the board
I2C_SDA: U8.4 (SDA); also elsewhere on the board
unnamed: D1.2 (A), R8.1
unnamed: D2.2 (A), R9.1
unnamed: D3.2 (A), R10.1
unnamed: D4.2 (A), R11.1
unnamed: D5.2 (A), R12.1
unnamed: D6.2 (A), F2.1
unnamed: D7.2 (A), R14.1
unnamed: F1.1, J7.1
unnamed: L2.1, U4.11 (L1)
unnamed: L2.2, U4.9 (L2)
unnamed: C16.1, U4.3 (VAUX)
unnamed: L3.1, U5.11 (L1)
unnamed: L3.2, U5.9 (L2)
unnamed: C17.1, U5.3 (VAUX)
unnamed: L4.1, U6.11 (L1)
unnamed: L4.2, U6.9 (L2)
unnamed: C24.1, U6.3 (VAUX)
SERVO_EN: U6.14 (EN); also elsewhere on the board
VBAT_SENSE: R15.1, R16.2; also elsewhere on the board
VBUS_5V: F2.2; also elsewhere on the board

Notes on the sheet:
POWER PATH CONTROLER
VOLTAGE SENSOR
SENSORS
5V FAULT
BUCK BOOST
3V3 FAULT
BATT IN
3V3 GOOD
3V3 BUCK BOST
5V GOOD
USB IN
BULK CAP
POWER INPUTS
CURRENT SENSOR
5V GENERAL BUCK BOST
5V SERVO BUCK BOST
DUAL POWER INPUTS WITH USB AND BATTERY INPUTS AVALIABLE. POLARITY PROTECTION ON THE BATTERY INPUT FOR ACIDENTAL MISCONECTS

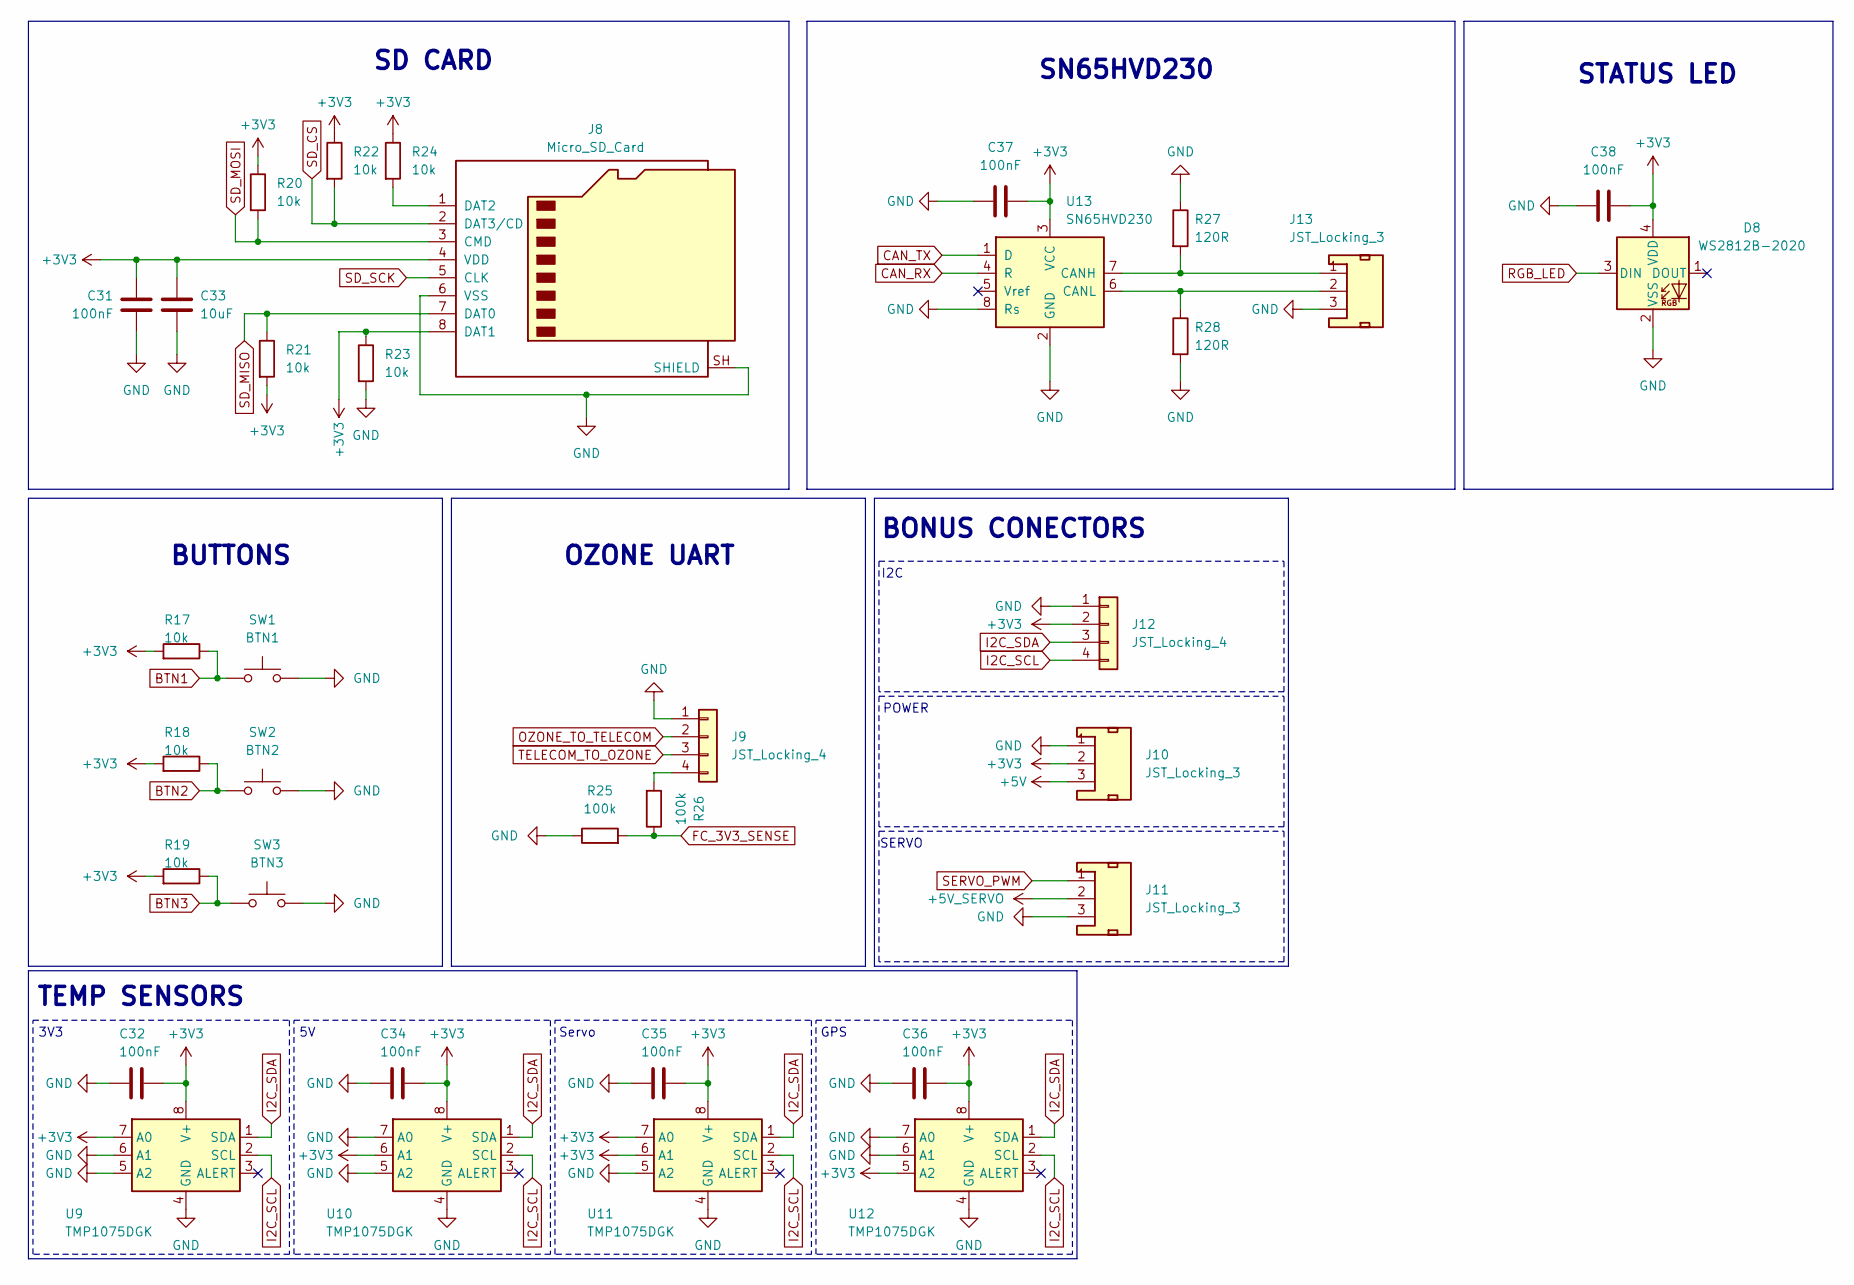
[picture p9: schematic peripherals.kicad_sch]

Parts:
C31, C32, C34, C35, C36: 100nF; C_0805_2012Metric
C33: 10uF; C_0805_2012Metric
C37, C38: 100nF; C_0603_1608Metric
D8: WS2812B-2020; LED_WS2812B-2020_PLCC4_2.0x2.0mm
J8: Micro_SD_Card; microSD_HC_Molex_47219-2001
J9, J12: JST_Locking_4; JST_1x04_P1.25mm_Locking_Horizontal_SMD
J10, J11, J13: JST_Locking_3; JST_1x03_P1.25mm_Locking_Horizontal_SMD
R17, R18, R19, R20, R21, R22, R23, R24: 10k; R_0603_1608Metric
R25, R26: 100k; R_0603_1608Metric
R27, R28: 120R; C_0805_2012Metric
SW1: BTN1; SW_Push_1P1T_NO_CK_KMR2
SW2: BTN2; SW_Push_1P1T_NO_CK_KMR2
SW3: BTN3; SW_Push_1P1T_NO_CK_KMR2
U9, U10, U11, U12: TMP1075DGK; VSSOP-8_3x3mm_P0.65mm
U13: SN65HVD230; SOIC-8_3.9x4.9mm_P1.27mm

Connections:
+3V3: C31.1, C32.1, C33.1, C34.1, C35.1, C36.1, C37.1, C38.1, D8.4 (VDD), J8.4 (VDD), J8.8 (DAT1), J10.2, J12.2, R17.2, R18.2, R19.2, R20.1, R21.2, R22.1, R23.1, R24.1, U9.7 (A0), U9.8 (V+), U10.6 (A1), U10.8 (V+), U11.6 (A1), U11.7 (A0), U11.8 (V+), U12.5 (A2), U12.8 (V+), U13.3 (VCC); also elsewhere on the board
+5V: J10.3; also elsewhere on the board
+5V_SERVO: J11.2; also elsewhere on the board
BTN1: R17.1, SW1.1; also elsewhere on the board
BTN2: R18.1, SW2.1; also elsewhere on the board
BTN3: R19.1, SW3.1; also elsewhere on the board
CAN_RX: U13.4 (R); also elsewhere on the board
CAN_TX: U13.1 (D); also elsewhere on the board
FC_3V3_SENSE: R25.2, R26.1; also elsewhere on the board
GND: C31.2, C32.2, C33.2, C34.2, C35.2, C36.2, C37.2, C38.2, D8.2 (VSS), J8.6 (VSS), J8.SH (SHIELD), J9.1, J10.1, J11.3, J12.1, J13.3, R23.2, R25.1, R27.1, R28.2, SW1.2, SW2.2, SW3.2, U9.4 (GND), U9.5 (A2), U9.6 (A1), U10.4 (GND), U10.5 (A2), U10.7 (A0), U11.4 (GND), U11.5 (A2), U12.4 (GND), U12.6 (A1), U12.7 (A0), U13.2 (GND), U13.8 (Rs); also elsewhere on the board
I2C_SCL: J12.4, U9.2 (SCL), U10.2 (SCL), U11.2 (SCL), U12.2 (SCL); also elsewhere on the board
I2C_SDA: J12.3, U9.1 (SDA), U10.1 (SDA), U11.1 (SDA), U12.1 (SDA); also elsewhere on the board
unnamed: J8.1 (DAT2), R24.2
unnamed: J9.4, R26.2
unnamed: J13.1, R27.2, U13.7 (CANH)
unnamed: J13.2, R28.1, U13.6 (CANL)
OZONE_TO_TELECOM: J9.2; also elsewhere on the board
RGB_LED: D8.3 (DIN); also elsewhere on the board
SD_CS: J8.2 (DAT3/CD), R22.2; also elsewhere on the board
SD_MISO: J8.7 (DAT0), R21.1; also elsewhere on the board
SD_MOSI: J8.3 (CMD), R20.2; also elsewhere on the board
SD_SCK: J8.5 (CLK); also elsewhere on the board
SERVO_PWM: J11.1; also elsewhere on the board
TELECOM_TO_OZONE: J9.3; also elsewhere on the board

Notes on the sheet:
STATUS LED
Servo
BONUS CONECTORS
TEMP SENSORS
I2C
POWER
3V3
BUTTONS
SN65HVD230
OZONE UART
SD CARD
SERVO
GPS

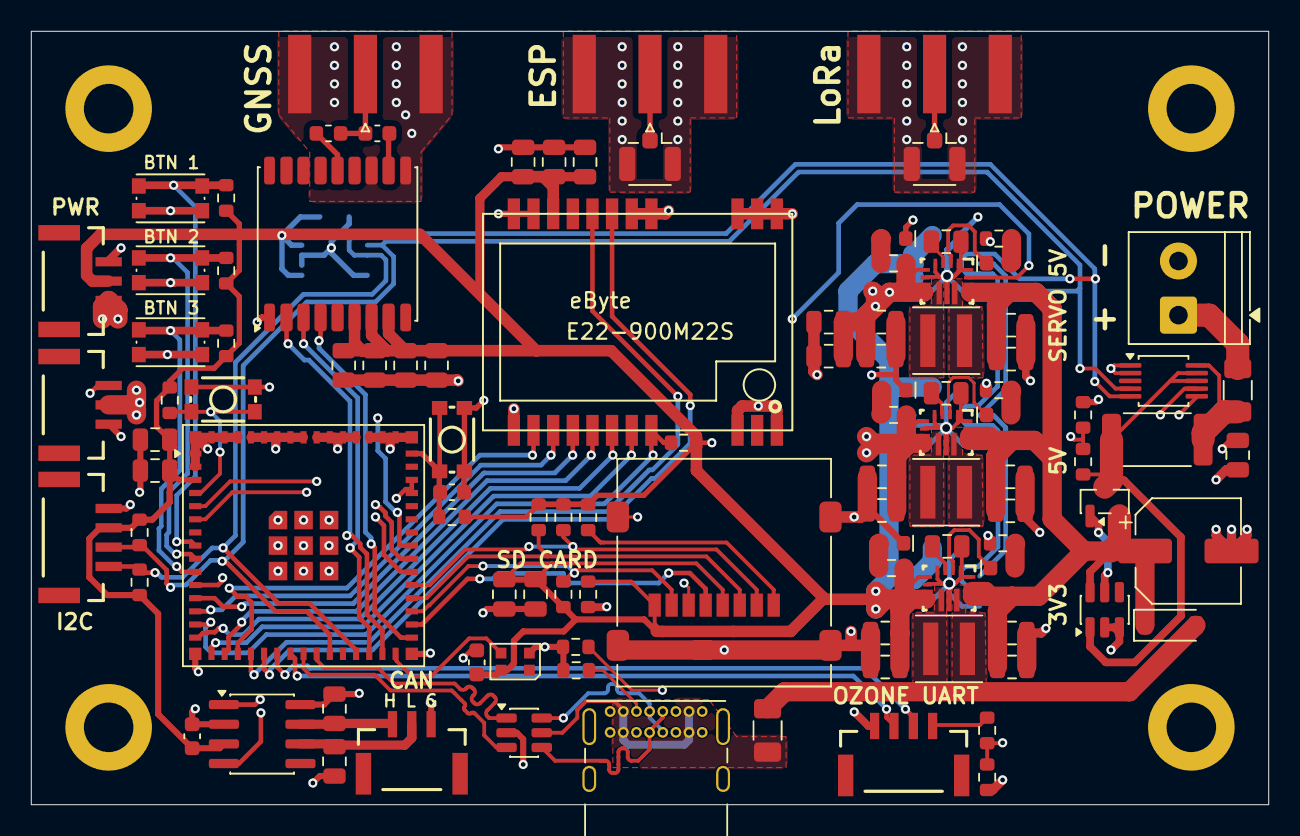
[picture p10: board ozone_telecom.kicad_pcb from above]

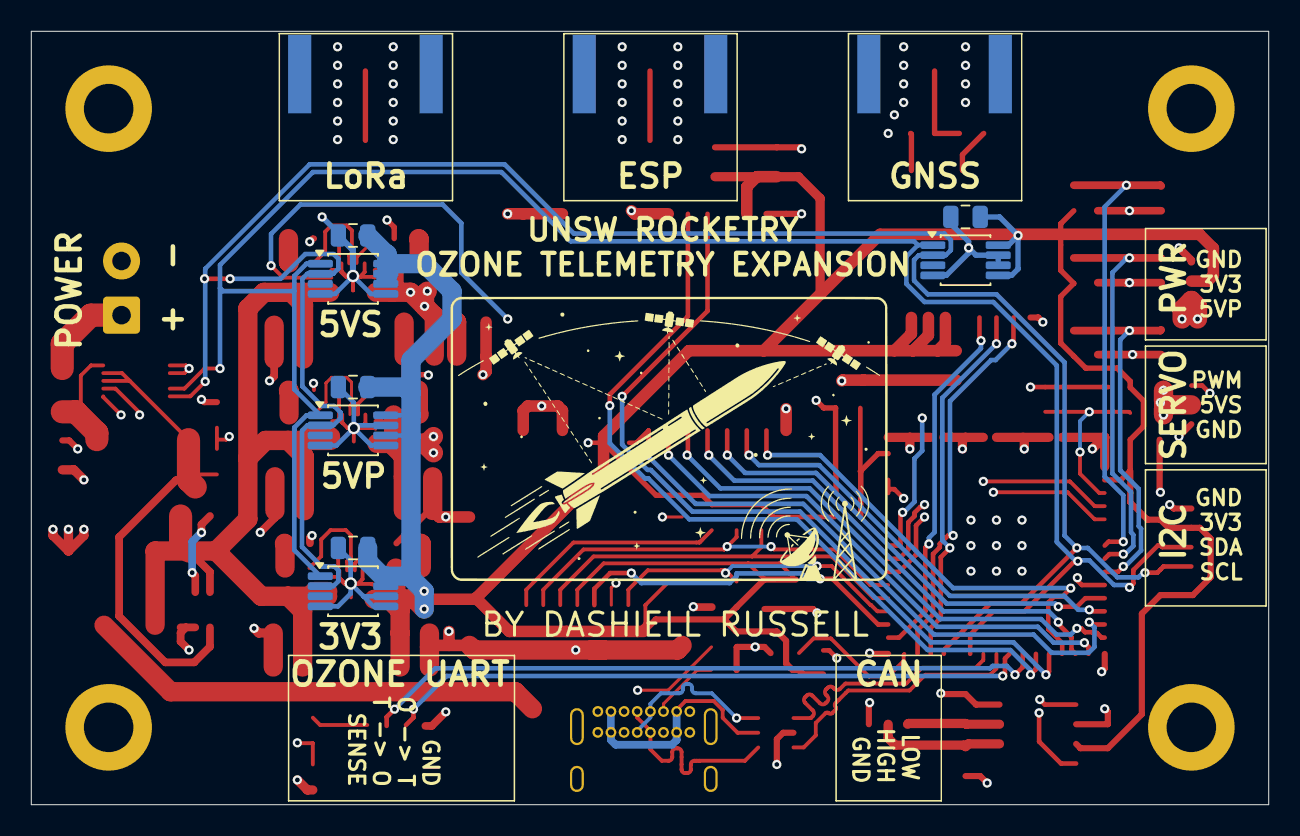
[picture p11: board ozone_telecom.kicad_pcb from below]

Board: 4 copper layers, 80.0 x 50.0 mm, 117 parts (8 on the bottom side), 76 nets.

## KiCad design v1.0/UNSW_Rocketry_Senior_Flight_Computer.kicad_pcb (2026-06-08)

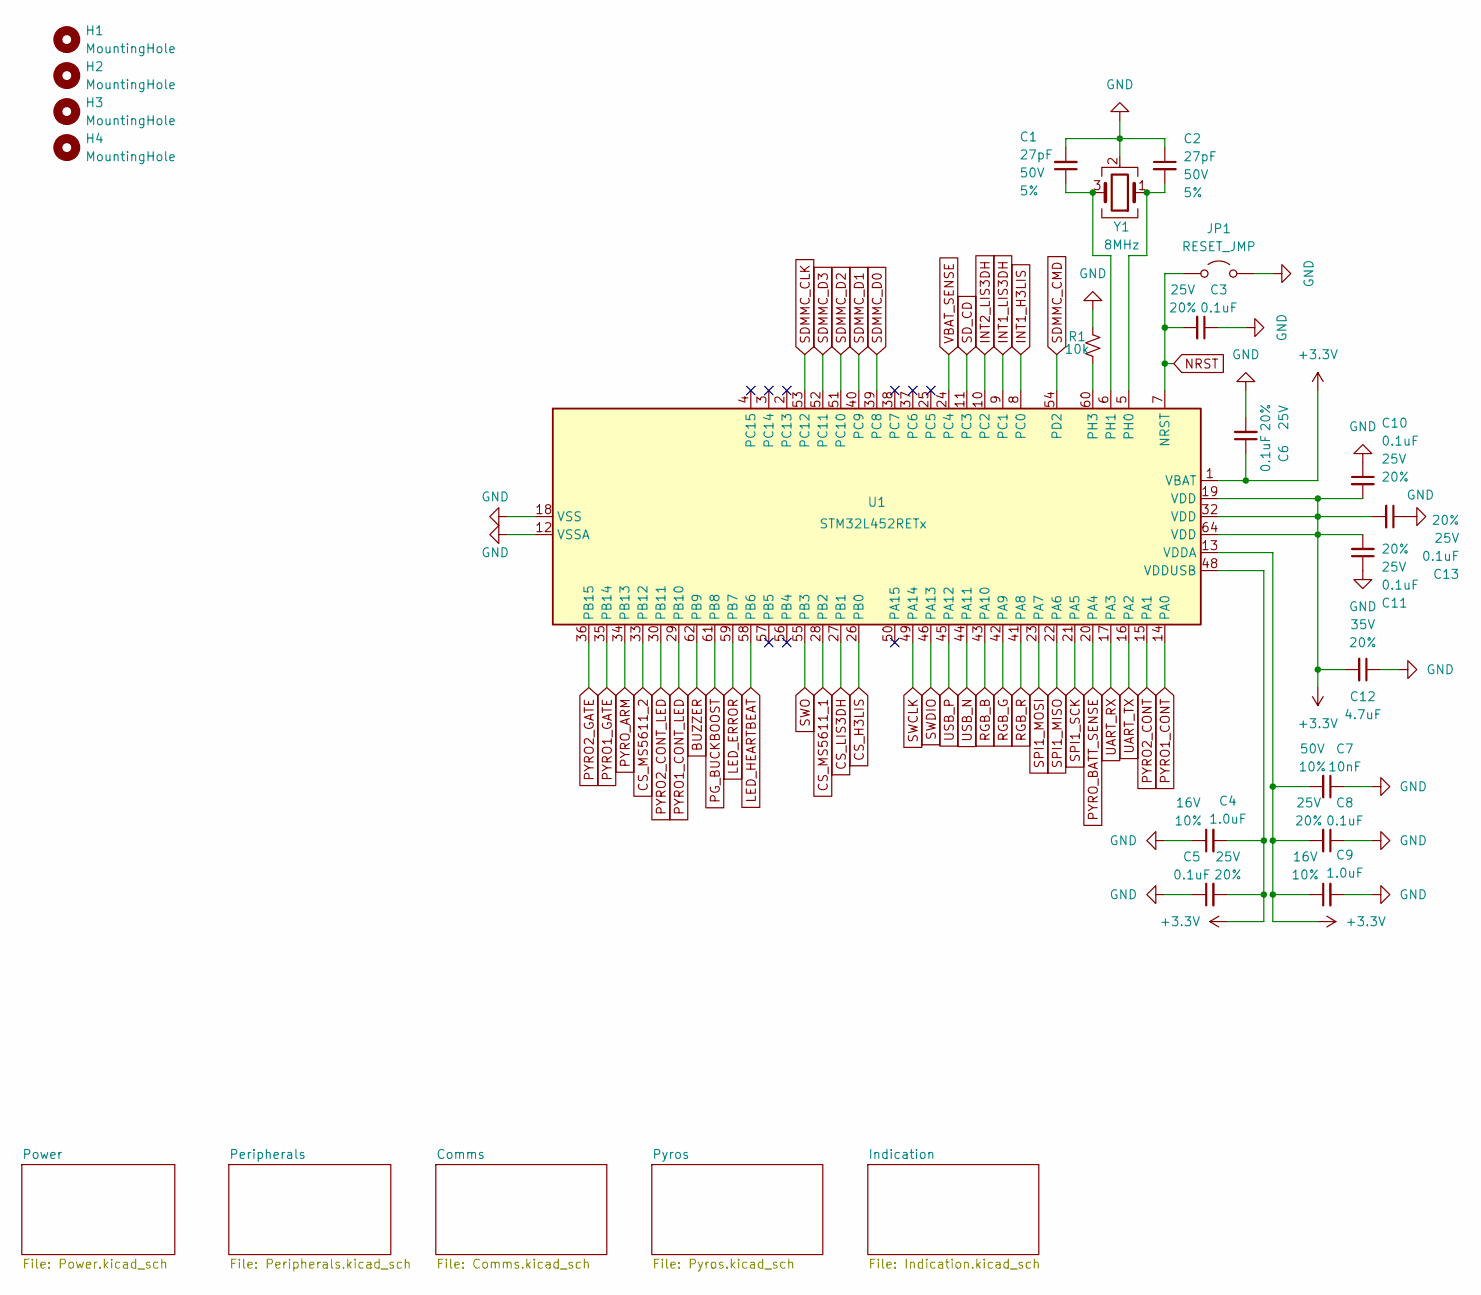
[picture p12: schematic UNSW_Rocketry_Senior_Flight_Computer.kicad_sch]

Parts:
C1, C2: 27pF; C_0603_1608Metric; Voltage 50V; Tolerance 5%
C3, C5, C6, C8, C10, C11, C13: 0.1uF; C_0603_1608Metric; Voltage 25V; Tolerance 20%
C4, C9: 1.0uF; C_0603_1608Metric; Voltage 16V; Tolerance 10%
C7: 10nF; C_0603_1608Metric; Voltage 50V; Tolerance 10%
C12: 4.7uF; C_0603_1608Metric; Voltage 35V; Tolerance 20%
H1, H2, H3, H4: MountingHole; MountingHole_3.2mm_M3_DIN965_Pad
JP1: RESET_JMP; TestPoint_2Pads_Pitch2.54mm_Drill0.8mm
R1: 10k; R_0603_1608Metric
U1: STM32L452RETx; LQFP-64_10x10mm_P0.5mm
Y1: 8MHz; Crystal_SMD_3225-4Pin_3.2x2.5mm; MPN ECS-80-18-33-JGN-TR; Digikey 50-ECS-80-18-33-JGN-CT-ND

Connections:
+3.3V: C4.2, C5.2, C6.1, C7.2, C8.2, C9.1, C10.2, C11.2, C12.2, C13.2, U1.1 (VBAT), U1.13 (VDDA), U1.19 (VDD), U1.32 (VDD), U1.48 (VDDUSB), U1.64 (VDD); also elsewhere on the board
BUZZER: U1.62 (PB9); also elsewhere on the board
CS_H3LIS: U1.26 (PB0); also elsewhere on the board
CS_LIS3DH: U1.27 (PB1); also elsewhere on the board
CS_MS5611_1: U1.28 (PB2); also elsewhere on the board
CS_MS5611_2: U1.33 (PB12); also elsewhere on the board
GND: C1.2, C2.1, C3.1, C4.1, C5.1, C6.2, C7.1, C8.1, C9.2, C10.1, C11.1, C12.1, C13.1, JP1.2 (B), R1.2, U1.12 (VSSA), U1.18 (VSS), U1.31 (VSS), U1.47 (VSS), U1.63 (VSS), Y1.2 (G), Y1.4 (G); also elsewhere on the board
INT1_H3LIS: U1.8 (PC0); also elsewhere on the board
INT1_LIS3DH: U1.9 (PC1); also elsewhere on the board
INT2_LIS3DH: U1.10 (PC2); also elsewhere on the board
LED_ERROR: U1.59 (PB7); also elsewhere on the board
LED_HEARTBEAT: U1.58 (PB6); also elsewhere on the board
NRST: C3.2, JP1.1 (A), U1.7 (NRST); also elsewhere on the board
unnamed: C2.2, U1.5 (PH0), Y1.1
unnamed: C1.1, U1.6 (PH1), Y1.3
unnamed: R1.1, U1.60 (PH3)
PG_BUCKBOOST: U1.61 (PB8); also elsewhere on the board
PYRO1_CONT: U1.14 (PA0); also elsewhere on the board
PYRO1_CONT_LED: U1.29 (PB10); also elsewhere on the board
PYRO1_GATE: U1.35 (PB14); also elsewhere on the board
PYRO2_CONT: U1.15 (PA1); also elsewhere on the board
PYRO2_CONT_LED: U1.30 (PB11); also elsewhere on the board
PYRO2_GATE: U1.36 (PB15); also elsewhere on the board
PYRO_ARM: U1.34 (PB13); also elsewhere on the board
PYRO_BATT_SENSE: U1.20 (PA4); also elsewhere on the board
RGB_B: U1.43 (PA10); also elsewhere on the board
RGB_G: U1.42 (PA9); also elsewhere on the board
RGB_R: U1.41 (PA8); also elsewhere on the board
SDMMC_CLK: U1.53 (PC12); also elsewhere on the board
SDMMC_CMD: U1.54 (PD2); also elsewhere on the board
SDMMC_D0: U1.39 (PC8); also elsewhere on the board
SDMMC_D1: U1.40 (PC9); also elsewhere on the board
SDMMC_D2: U1.51 (PC10); also elsewhere on the board
SDMMC_D3: U1.52 (PC11); also elsewhere on the board
SD_CD: U1.11 (PC3); also elsewhere on the board
SPI1_MISO: U1.22 (PA6); also elsewhere on the board
SPI1_MOSI: U1.23 (PA7); also elsewhere on the board
SPI1_SCK: U1.21 (PA5); also elsewhere on the board
SWCLK: U1.49 (PA14); also elsewhere on the board
SWDIO: U1.46 (PA13); also elsewhere on the board
SWO: U1.55 (PB3); also elsewhere on the board
UART_RX: U1.17 (PA3); also elsewhere on the board
UART_TX: U1.16 (PA2); also elsewhere on the board
USB_N: U1.44 (PA11); also elsewhere on the board
USB_P: U1.45 (PA12); also elsewhere on the board
VBAT_SENSE: U1.24 (PC4); also elsewhere on the board

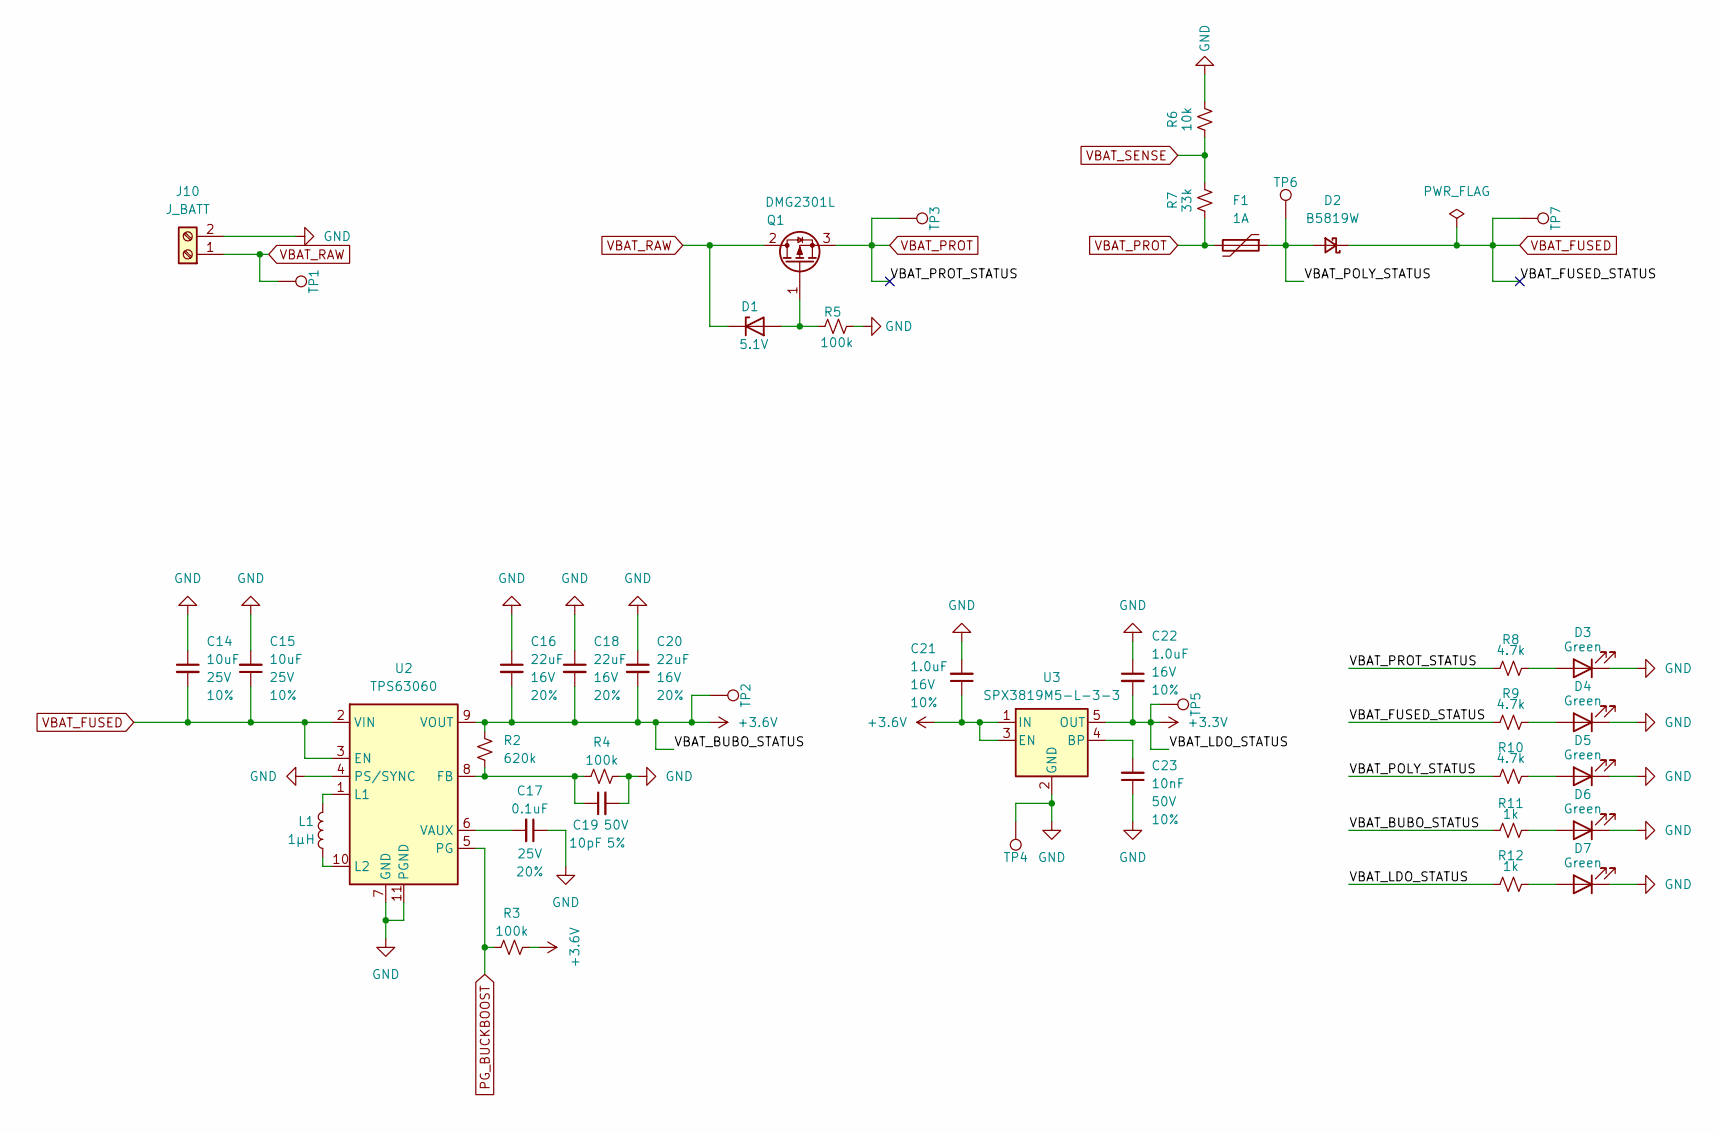
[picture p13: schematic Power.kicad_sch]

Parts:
C14, C15: 10uF; C_0805_2012Metric; Voltage 25V; Tolerance 10%
C16, C18, C20: 22uF; C_0805_2012Metric; Voltage 16V; Tolerance 20%
C17: 0.1uF; C_0603_1608Metric; Voltage 25V; Tolerance 20%
C19: 10pF; C_0603_1608Metric; Voltage 50V; Tolerance 5%
C21, C22: 1.0uF; C_0603_1608Metric; Voltage 16V; Tolerance 10%
C23: 10nF; C_0603_1608Metric; Voltage 50V; Tolerance 10%
D1: 5.1V; D_SOD-323
D2: B5819W; D_SOD-123
D3, D4, D5, D6, D7: Green; LED_0603_1608Metric
F1: 1A; Fuse_1206_3216Metric
J10: J_BATT; TerminalBlock_Phoenix_PT-1,5-2-3.5-H_1x02_P3.50mm_Horizontal
L1: 1µH; L_Coilcraft_XxL4020
Q1: DMG2301L; SOT-23; Digi DMG2301L-7DITR-ND
R2: 620k; R_0603_1608Metric
R3, R4, R5: 100k; R_0603_1608Metric
R6: 10k; R_0603_1608Metric
R7: 33k; R_0603_1608Metric
R8, R9, R10: 4.7k; R_0603_1608Metric
R11, R12: 1k; R_0603_1608Metric
TP1, TP2, TP3, TP4, TP5, TP6, TP7: 1.0mm; TestPoint-1.0mm
U2: TPS63060; Texas_S-PWSON-N10_ThermalVias
U3: SPX3819M5-L-3-3; SOT-23-5

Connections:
+3.3V: C22.2, R12.1, TP5.1 (1_1), U3.5 (OUT); also elsewhere on the board
+3.6V: C16.2, C18.2, C20.2, C21.1, R2.1, R3.1, R11.1, TP2.1 (1_1), U2.9 (VOUT), U3.1 (IN), U3.3 (EN)
/Power/VBAT_POLY_STATUS: D2.2 (A), F1.1, R10.1, TP6.1 (1_1)
GND: C14.1, C15.2, C16.1, C17.1, C18.1, C19.2, C20.1, C21.2, C22.1, C23.1, D3.1 (K), D4.1 (K), D5.1 (K), D6.1 (K), D7.1 (K), J10.2, R4.1, R5.2, R6.2, TP4.1 (1_1), U2.4 (PS/SYNC), U2.7 (GND), U2.11 (PGND), U3.2 (GND); also elsewhere on the board
unnamed: D1.2 (A), Q1.1 (G), R5.1
unnamed: D3.2 (A), R8.2
unnamed: D4.2 (A), R9.2
unnamed: D5.2 (A), R10.2
unnamed: D6.2 (A), R11.2
unnamed: D7.2 (A), R12.2
unnamed: C19.1, R2.2, R4.2, U2.8 (FB)
unnamed: L1.2, U2.1 (L1)
unnamed: L1.1, U2.10 (L2)
unnamed: C17.2, U2.6 (VAUX)
unnamed: C23.2, U3.4 (BP)
PG_BUCKBOOST: R3.2, U2.5 (PG); also elsewhere on the board
VBAT_FUSED: C14.2, C15.1, D2.1 (K), R9.1, TP7.1 (1_1), U2.2 (VIN), U2.3 (EN); also elsewhere on the board
VBAT_PROT: F1.2, Q1.3 (S), R7.1, R8.1, TP3.1 (1_1)
VBAT_RAW: D1.1 (K), J10.1, Q1.2 (D), TP1.1 (1_1)
VBAT_SENSE: R6.1, R7.2; also elsewhere on the board

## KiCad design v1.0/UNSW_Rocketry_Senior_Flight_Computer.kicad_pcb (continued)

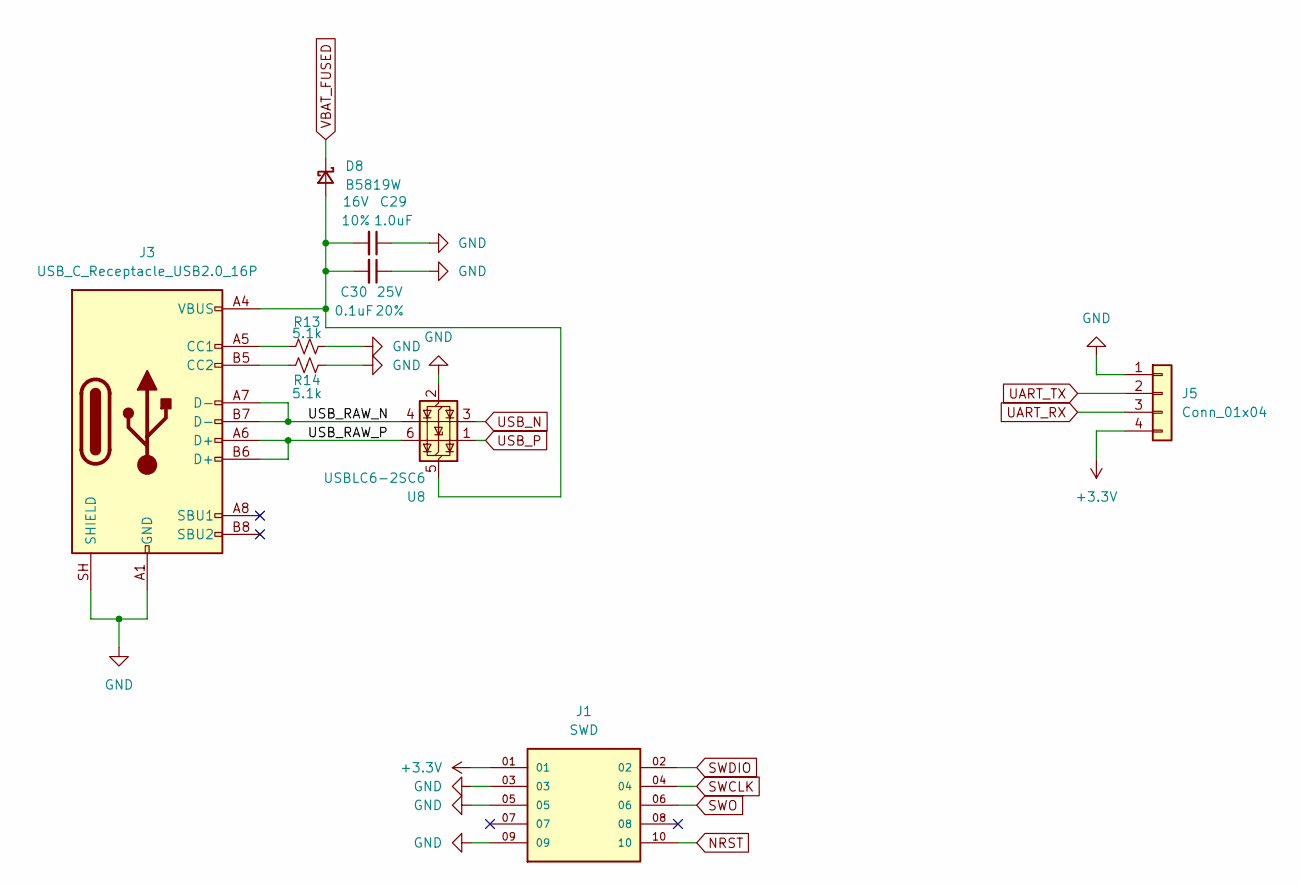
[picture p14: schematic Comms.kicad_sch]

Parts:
C29: 1.0uF; C_0603_1608Metric; Voltage 16V; Tolerance 10%
C30: 0.1uF; C_0603_1608Metric; Voltage 25V; Tolerance 20%
D8: B5819W; D_SOD-123
J1: SWD; SAMTEC_FTSH-105-01-X-DV-K-X; PARTREV H
J3: USB_C_Receptacle_USB2.0_16P; USB_C_Receptacle_GCT_USB4085
J5: Conn_01x04; Molex_PicoBlade_53047-0410_1x04_P1.25mm_Vertical
R13, R14: 5.1k; R_0603_1608Metric
U8: USBLC6-2SC6; SOT-23-6

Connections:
+3.3V: J1.01, J5.4; also elsewhere on the board
/Comms/USB_RAW_N: J3.A7 (D-), J3.B7 (D-), U8.4 (I/O2)
/Comms/USB_RAW_P: J3.A6 (D+), J3.B6 (D+), U8.6 (I/O1)
GND: C29.1, C30.1, J1.03, J1.05, J1.09, J3.A1 (GND), J3.A12 (GND), J3.B1 (GND), J3.B12 (GND), J3.SH (SHIELD), J5.1, R13.2, R14.2, U8.2 (GND); also elsewhere on the board
NRST: J1.10; also elsewhere on the board
unnamed: C29.2, C30.2, D8.2 (A), J3.A4 (VBUS), J3.A9 (VBUS), J3.B4 (VBUS), J3.B9 (VBUS), U8.5 (VBUS)
unnamed: J3.A5 (CC1), R13.1
unnamed: J3.B5 (CC2), R14.1
SWCLK: J1.04; also elsewhere on the board
SWDIO: J1.02; also elsewhere on the board
SWO: J1.06; also elsewhere on the board
UART_RX: J5.3; also elsewhere on the board
UART_TX: J5.2; also elsewhere on the board
USB_N: U8.3 (I/O2); also elsewhere on the board
USB_P: U8.1 (I/O1); also elsewhere on the board
VBAT_FUSED: D8.1 (K); also elsewhere on the board

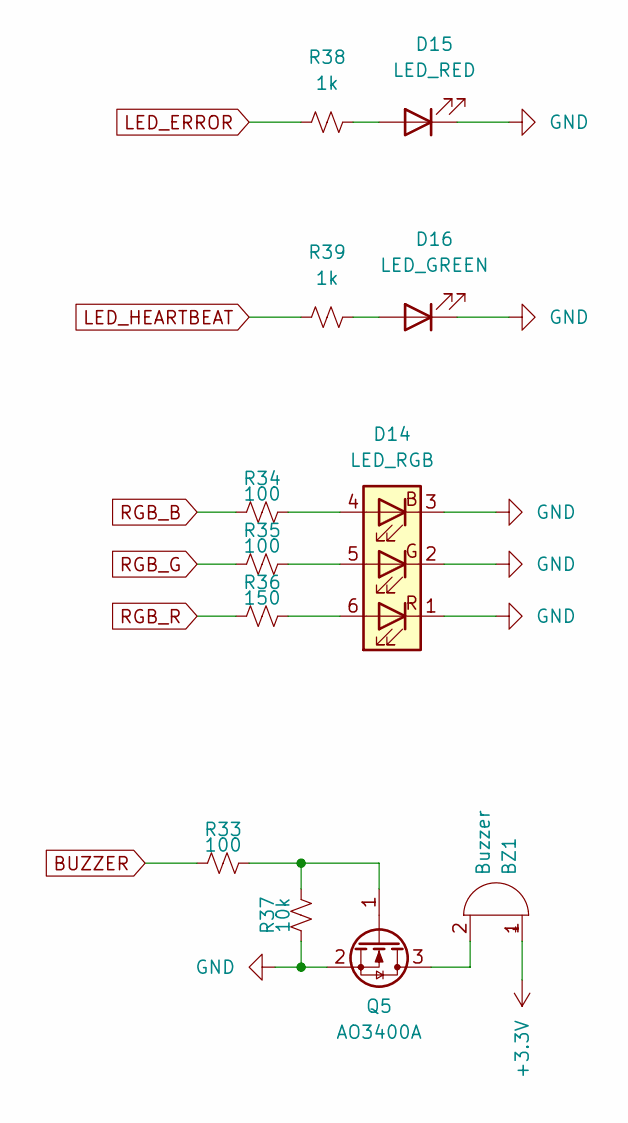
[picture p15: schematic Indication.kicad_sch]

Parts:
BZ1: Buzzer; Buzzer_CUI_CPT-9019S-SMT
D14: LED_RGB; LED_RGB_5050-6
D15: LED_RED; LED_0603_1608Metric_Pad1.05x0.95mm_HandSolder
D16: LED_GREEN; LED_0603_1608Metric_Pad1.05x0.95mm_HandSolder
Q5: AO3400A; SOT-23
R33, R34, R35: 100; R_0603_1608Metric
R36: 150; R_0603_1608Metric
R37: 10k; R_0603_1608Metric
R38, R39: 1k; R_0603_1608Metric

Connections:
+3.3V: BZ1.1 (+); also elsewhere on the board
BUZZER: R33.1; also elsewhere on the board
GND: D14.1 (RK), D14.2 (GK), D14.3 (BK), D15.1 (K), D16.1 (K), Q5.2 (S), R37.1; also elsewhere on the board
LED_ERROR: R38.1; also elsewhere on the board
LED_HEARTBEAT: R39.1; also elsewhere on the board
unnamed: BZ1.2 (-), Q5.3 (D)
unnamed: D14.4 (BA), R34.2
unnamed: D14.5 (GA), R35.2
unnamed: D14.6 (RA), R36.2
unnamed: D15.2 (A), R38.2
unnamed: D16.2 (A), R39.2
unnamed: Q5.1 (G), R33.2, R37.2
RGB_B: R34.1; also elsewhere on the board
RGB_G: R35.1; also elsewhere on the board
RGB_R: R36.1; also elsewhere on the board

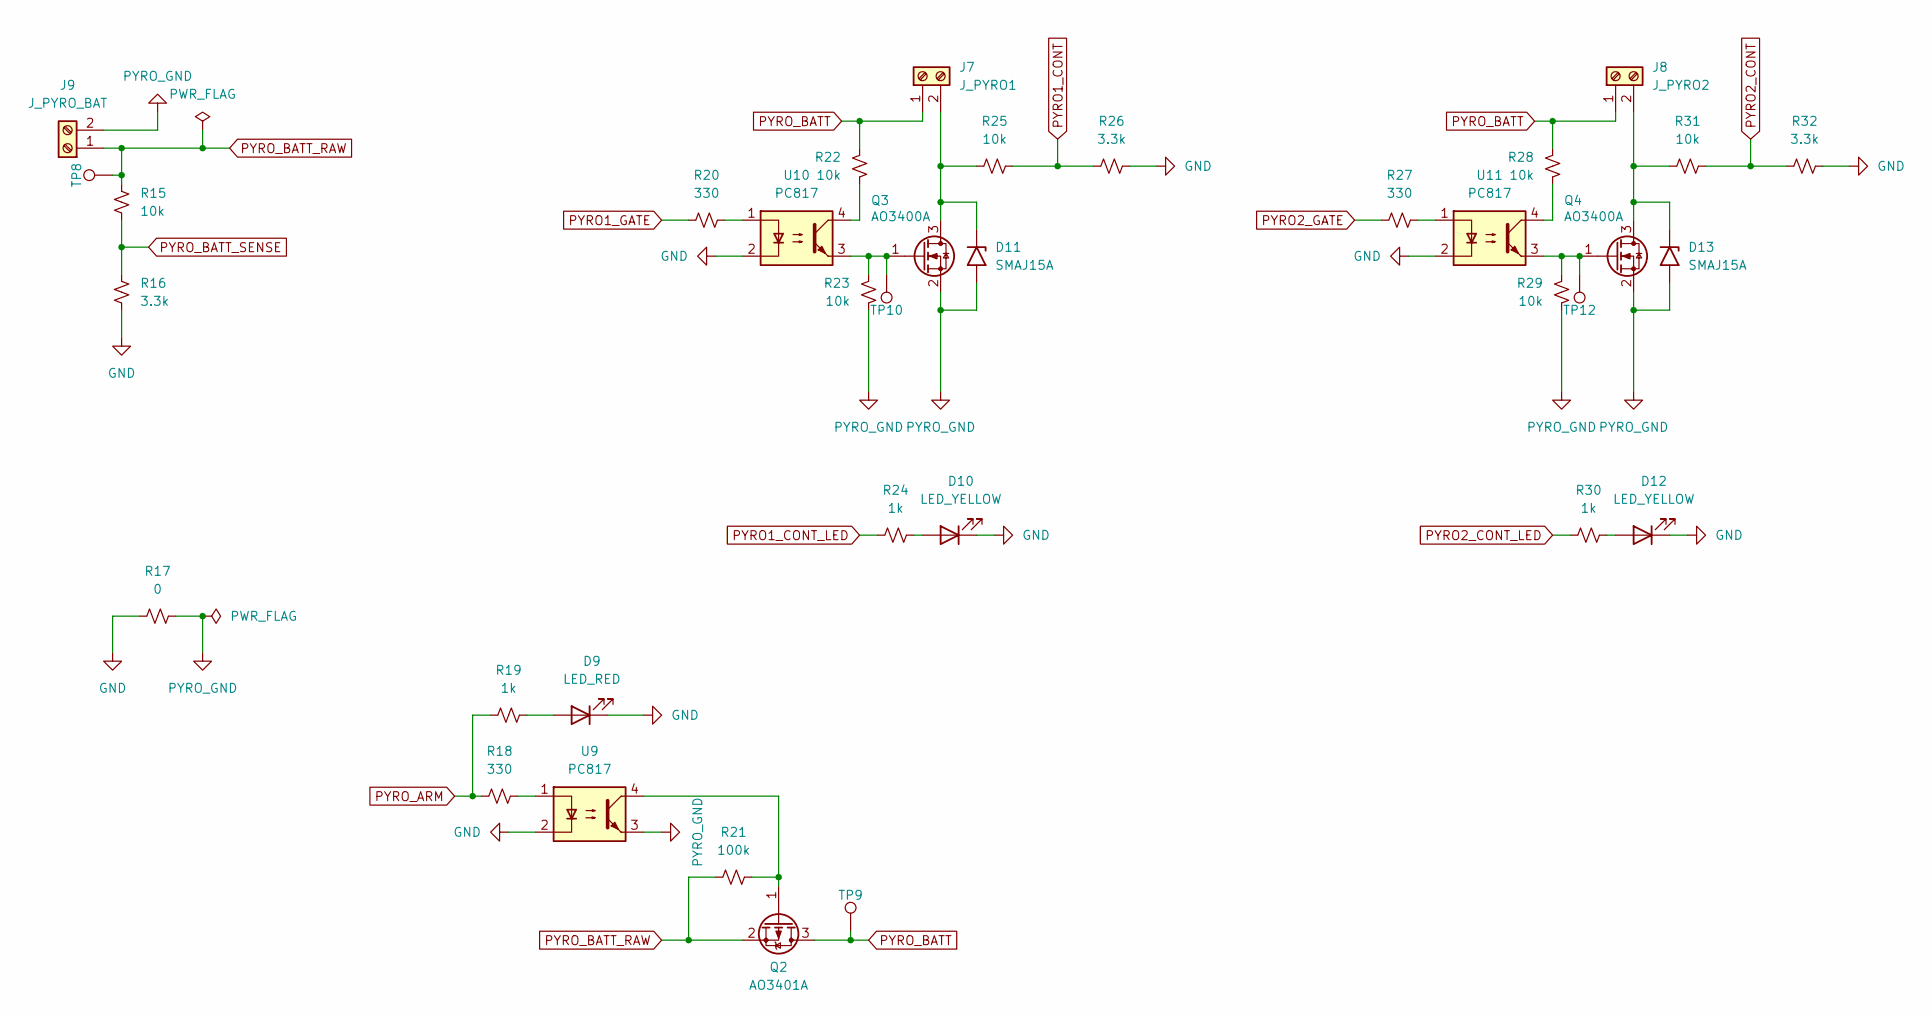
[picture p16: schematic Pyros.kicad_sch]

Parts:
D9: LED_RED; LED_0603_1608Metric_Pad1.05x0.95mm_HandSolder
D10, D12: LED_YELLOW; LED_0603_1608Metric_Pad1.05x0.95mm_HandSolder
D11, D13: SMAJ15A; D_SMA
J7: J_PYRO1; TerminalBlock_Phoenix_PT-1,5-2-3.5-H_1x02_P3.50mm_Horizontal
J8: J_PYRO2; TerminalBlock_Phoenix_PT-1,5-2-3.5-H_1x02_P3.50mm_Horizontal
J9: J_PYRO_BAT; TerminalBlock_Phoenix_PT-1,5-2-3.5-H_1x02_P3.50mm_Horizontal
Q2: AO3401A; SOT-23
Q3, Q4: AO3400A; SOT-23
R15, R22, R23, R25, R28, R29, R31: 10k; R_0603_1608Metric
R16, R26, R32: 3.3k; R_0603_1608Metric
R17: 0; R_0603_1608Metric
R18, R20, R27: 330; R_0603_1608Metric
R19, R24, R30: 1k; R_0603_1608Metric
R21: 100k; R_0603_1608Metric
TP8, TP9, TP10, TP12: 1.0mm; TestPoint-1.0mm
U9, U10, U11: PC817; DIP-4_W7.62mm

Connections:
GND: D9.1 (K), D10.1 (K), D12.1 (K), R16.2, R17.1, R26.1, R32.1, U9.2, U10.2, U11.2; also elsewhere on the board
unnamed: D9.2 (A), R19.1
unnamed: D10.2 (A), R24.1
unnamed: D11.1 (A1), J7.2, Q3.3 (D), R25.2
unnamed: D12.2 (A), R30.1
unnamed: D13.1 (A1), J8.2, Q4.3 (D), R31.2
unnamed: Q2.1 (G), R21.1, U9.4
unnamed: Q3.1 (G), R23.1, TP10.1 (1_1), U10.3
unnamed: Q4.1 (G), R29.1, TP12.1 (1_1), U11.3
unnamed: R18.2, U9.1
unnamed: R20.2, U10.1
unnamed: R22.2, U10.4
unnamed: R27.2, U11.1
unnamed: R28.2, U11.4
PYRO1_CONT: R25.1, R26.2; also elsewhere on the board
PYRO1_CONT_LED: R24.2; also elsewhere on the board
PYRO1_GATE: R20.1; also elsewhere on the board
PYRO2_CONT: R31.1, R32.2; also elsewhere on the board
PYRO2_CONT_LED: R30.2; also elsewhere on the board
PYRO2_GATE: R27.1; also elsewhere on the board
PYRO_ARM: R18.1, R19.2; also elsewhere on the board
PYRO_BATT: J7.1, J8.1, Q2.3 (D), R22.1, R28.1, TP9.1 (1_1)
PYRO_BATT_RAW: J9.1, Q2.2 (S), R15.1, R21.2, TP8.1 (1_1)
PYRO_BATT_SENSE: R15.2, R16.1; also elsewhere on the board
PYRO_GND: D11.2 (A2), D13.2 (A2), J9.2, Q3.2 (S), Q4.2 (S), R17.2, R23.2, R29.2, U9.3

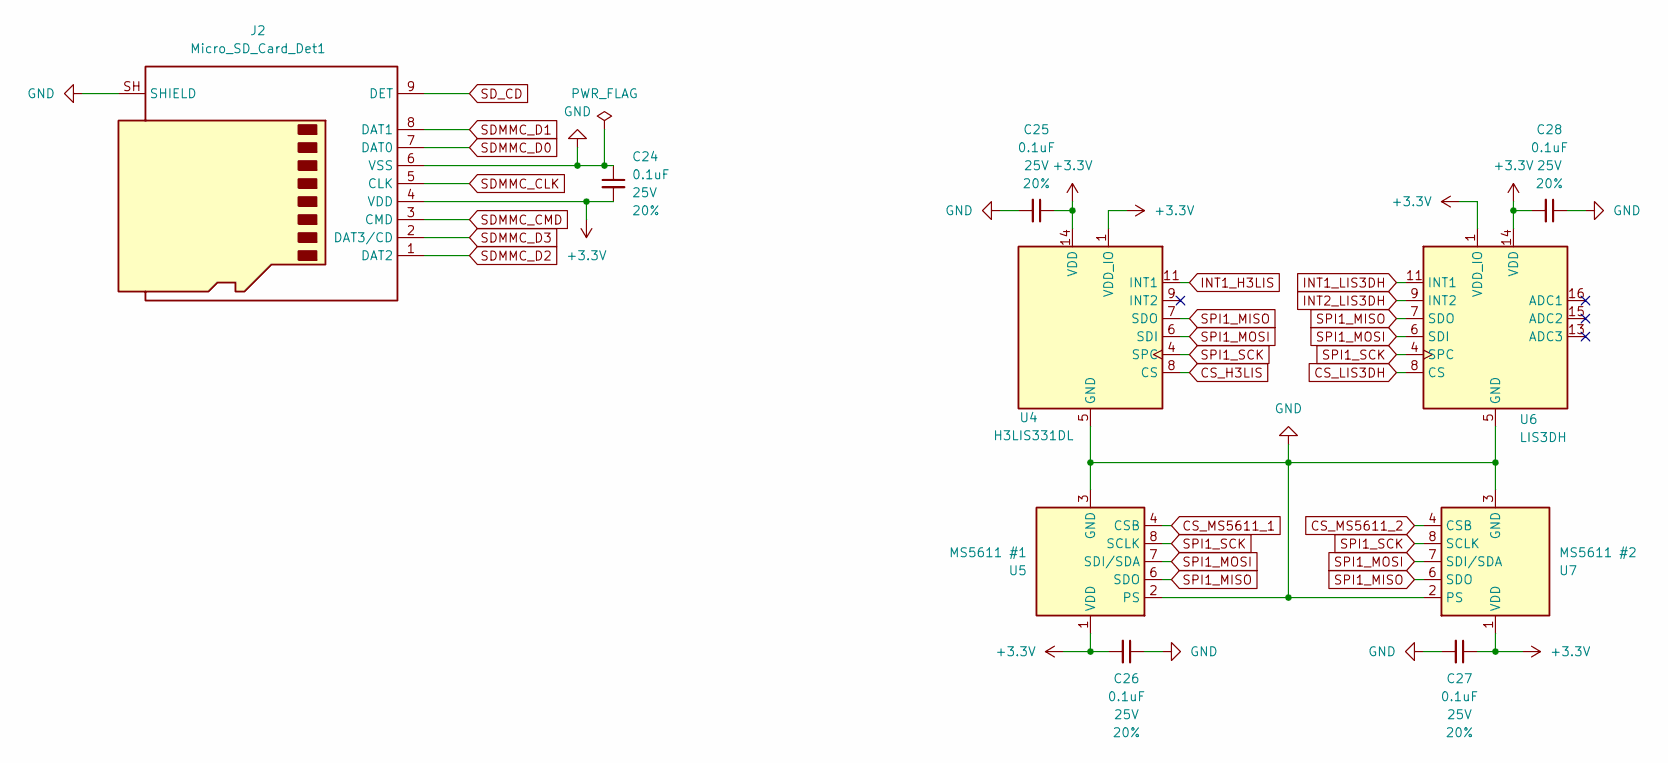
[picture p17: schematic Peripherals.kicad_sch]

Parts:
C24, C25, C26, C27, C28: 0.1uF; C_0603_1608Metric; Voltage 25V; Tolerance 20%
J2: Micro_SD_Card_Det1; microSD_HC_Hirose_DM3AT-SF-PEJM5
U4: H3LIS331DL; LGA-16_3x3mm_P0.5mm_LayoutBorder3x5y
U5: MS5611 #1; LGA-8_3x5mm_P1.25mm
U6: LIS3DH; LGA-16_3x3mm_P0.5mm_LayoutBorder3x5y
U7: MS5611 #2; LGA-8_3x5mm_P1.25mm

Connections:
+3.3V: C24.2, C25.1, C26.2, C27.1, C28.2, J2.4 (VDD), U4.1 (VDD_IO), U4.14 (VDD), U4.15 (VDD), U5.1 (VDD), U6.1 (VDD_IO), U6.14 (VDD), U7.1 (VDD); also elsewhere on the board
CS_H3LIS: U4.8 (CS); also elsewhere on the board
CS_LIS3DH: U6.8 (CS); also elsewhere on the board
CS_MS5611_1: U5.4 (CSB), U5.5 (CSB); also elsewhere on the board
CS_MS5611_2: U7.4 (CSB), U7.5 (CSB); also elsewhere on the board
GND: C24.1, C25.2, C26.1, C27.2, C28.1, J2.6 (VSS), J2.SH (SHIELD), U4.5 (GND), U4.10 (GND), U4.12 (GND), U4.13 (GND), U4.16 (GND), U5.2 (PS), U5.3 (GND), U6.5 (GND), U6.10 (GND), U6.12 (GND), U7.2 (PS), U7.3 (GND); also elsewhere on the board
INT1_H3LIS: U4.11 (INT1); also elsewhere on the board
INT1_LIS3DH: U6.11 (INT1); also elsewhere on the board
INT2_LIS3DH: U6.9 (INT2); also elsewhere on the board
SDMMC_CLK: J2.5 (CLK); also elsewhere on the board
SDMMC_CMD: J2.3 (CMD); also elsewhere on the board
SDMMC_D0: J2.7 (DAT0); also elsewhere on the board
SDMMC_D1: J2.8 (DAT1); also elsewhere on the board
SDMMC_D2: J2.1 (DAT2); also elsewhere on the board
SDMMC_D3: J2.2 (DAT3/CD); also elsewhere on the board
SD_CD: J2.9 (DET); also elsewhere on the board
SPI1_MISO: U4.7 (SDO), U5.6 (SDO), U6.7 (SDO), U7.6 (SDO); also elsewhere on the board
SPI1_MOSI: U4.6 (SDI), U5.7 (SDI/SDA), U6.6 (SDI), U7.7 (SDI/SDA); also elsewhere on the board
SPI1_SCK: U4.4 (SPC), U5.8 (SCLK), U6.4 (SPC), U7.8 (SCLK); also elsewhere on the board

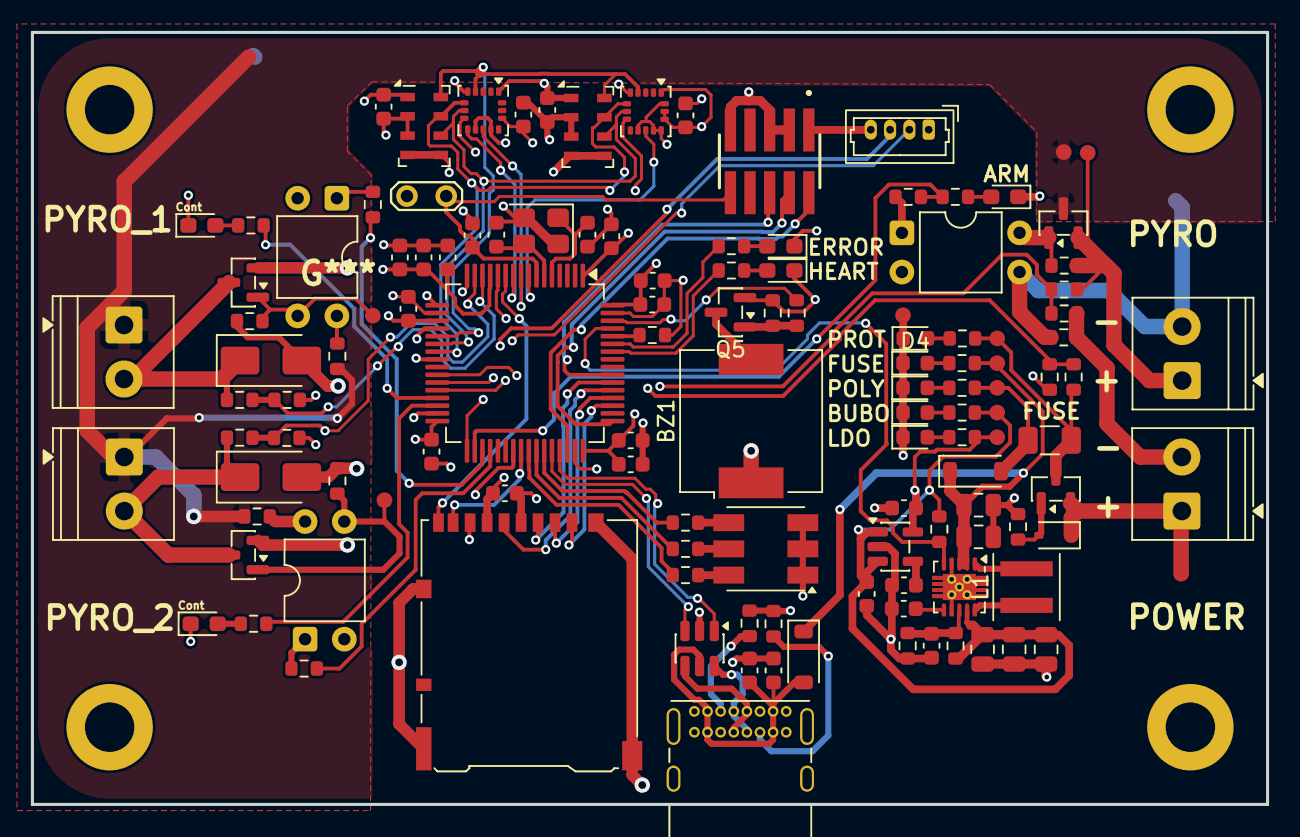
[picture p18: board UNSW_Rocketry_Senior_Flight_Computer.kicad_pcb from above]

Board: 4 copper layers, 80.0 x 50.0 mm, 129 parts (0 on the bottom side), 90 nets.

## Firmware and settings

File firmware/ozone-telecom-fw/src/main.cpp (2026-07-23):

/**
 * OZONE TELECOM hub firmware — main.cpp
 *
 * Job: be a dumb, fast, concurrent pipe between the STM32 flight computer's
 * FCD/1 text link (UART) and three independent radio links (WiFi/WebSocket,
 * BLE/NUS, LoRa/E22), plus inject the local GNSS fix as extra TLM fields.
 * Every line received from the FC is also mirrored to this board's own
 * microSD (sd_log.cpp) as a second, independent flight record, backing up
 * the FC's own OZONE*.CSV SD log in case that card is ever lost or damaged.
 *
 * SAFETY CONTRACT (read docs/telecom-command-protocol.md and
 * firmware/ozone-fw/app/Inc/pyro_trigger.h before touching this file):
 *   - This hub NEVER originates, rewrites, filters, or auto-repeats any
 *     command line. Every `do ...` / `set ...` / `whoami` byte that arrives
 *     from WiFi, BLE, or LoRa is forwarded to the FC UART **verbatim**,
 *     character for character, once.
 *   - The FC alone enforces arm state, key-switch continuity, token/CRC/seq
 *     checks, and fire_mode interlocks (pyro_trigger.c). This hub has no
 *     opinion on pyro safety and must never grow one — no "helpful" retry,
 *     no caching of the last fire command, no local echo-back of a token.
 *   - Any bug here should fail *closed* (drop a line) rather than *open*
 *     (invent, duplicate, or delay-then-fire a line).
 *
 * Concurrency: WiFi (WebSocket) and BLE share the ESP32-S3's single 2.4 GHz
 * radio, time-sliced by the coexistence firmware inside arduino-esp32/IDF —
 * fine at the low, bursty data rates here (short text lines, a few Hz).
 * LoRa (E22/SX1262) is a completely separate 915 MHz radio on its own SPI
 * bus, so it runs fully independently of the 2.4 GHz side.
 */
#include <Arduino.h>
#include "../include/config.h"
#include "fc_link.h"
#include "ws_link.h"
#include "ble_nus.h"
#include "lora_link.h"
#include "gnss_link.h"
#include "sd_log.h"

namespace {

// Rate-limit the GNSS TLM injection so it doesn't dominate the (slow) LoRa
// link; WiFi/BLE can obviously take much more, but a single injection rate
// keeps the three links' views of "the stream" consistent.
uint32_t last_gnss_emit_ms = 0;
constexpr uint32_t GNSS_EMIT_PERIOD_MS = 1000; // 1 Hz

// --- Fan-out from the FC (or from GNSS) to all three downlinks -------------
void fanOutToAllLinks(const String &line) {
    ws_send_line(line);
    ble_nus_send_line(line);
    lora_send_line(line);
}

// --- Callbacks: a command line arrived on some uplink -> relay to the FC ---
// Every one of these does the exact same thing on purpose: forward verbatim,
// no branching on content. Do not add `if (line.startsWith("do fire"))`
// special-casing here — that is the FC's job, not this hub's.
void onLineFromWs(const String &line)   { fc_link_send_line(line); }
void onLineFromBle(const String &line)  { fc_link_send_line(line); }
void onLineFromLora(const String &line) { fc_link_send_line(line); }

// --- Callback: a line arrived from the FC -> fan out + SD backup ----------
// Every line the FC sends (TLM/EVT/LOG/PARAM/ACK/FCD1) goes to the three
// radio downlinks *and* to the telecom board's own microSD (sd_log.cpp) as
// an independent backup copy of the flight — mirroring the FC's own SD log.
// sd_log_line() is a fast RAM-buffer append (or true no-op with no card
// present); it never blocks, so it can't become the slowest link in this
// fan-out and can't stall the radio relay.
void onLineFromFc(const String &line) {
    fanOutToAllLinks(line);
    sd_log_line(line.c_str());

    // Flight events (LAUNCH/APOGEE/DEPLOY/PYRO/LANDED — see
    // firmware/tools/gcs/PROTOCOL.md) are rare and safety-relevant: force
    // them to the card immediately instead of waiting for the next timed
    // flush, so a power loss right after e.g. LANDED doesn't cost this
    // backup its most important line. Cheap to do — EVT lines are
    // infrequent by nature.
    if (line.startsWith("EVT ")) {
        sd_log_flush();
    }
}

} // namespace

void setup() {
    Serial.begin(115200); // USB debug console only — not part of the FCD fan-out
    delay(200);
    Serial.println("OZONE TELECOM hub booting...");

    fc_link_init();
    gnss_init();
    wifi_ws_init();
    ble_nus_init();

    if (!lora_init()) {
        Serial.println("LoRa init FAILED — check E22 wiring/config.h pins");
        // Deliberately continue: WiFi/BLE fan-out and the FC UART relay
        // should still work even if LoRa hardware isn't present/working on
        // the bench. LoRa failures are logged, not fatal.
    }

    if (!sd_log_init()) {
        Serial.println("SD backup log NOT active (no/bad card on J8) — "
                        "relay unaffected, this is a best-effort backup only");
        // Same "log it, don't halt" treatment as LoRa above: the SD backup
        // is a nice-to-have second copy of the flight, never a dependency
        // of the actual comms-relay job this hub exists to do.
    }

    Serial.println("OZONE TELECOM hub up.");
}

void loop() {
    // 1) FC -> everywhere (telemetry, logs, acks)
    fc_link_poll(onLineFromFc);

    // 2) everywhere -> FC (commands), each transport polled independently so
    //    none can starve another (all non-blocking).
    ws_poll(onLineFromWs);
    ble_nus_poll(onLineFromBle);
    lora_poll(onLineFromLora);

    // 3) local GNSS fix -> extra TLM line, fanned out same as FC telemetry.
    //    (Not written to the SD backup — that file is meant to be a mirror
    //    of the FC's own record, and the GNSS fix is hub-local data the FC
    //    never saw; keep the backup an honest copy of the FCD stream only.)
    gnss_poll();
    uint32_t now = millis();
    if (now - last_gnss_emit_ms >= GNSS_EMIT_PERIOD_MS) {
        String gnssLine;
        if (gnss_build_tlm_line(gnssLine)) {
            fanOutToAllLinks(gnssLine);
        }
        last_gnss_emit_ms = now;
    }

    // 4) SD backup: flush the RAM-buffered FC lines to the microSD on a
    //    timer (sd_log.cpp) — never blocks the relay above.
    sd_log_poll();
}

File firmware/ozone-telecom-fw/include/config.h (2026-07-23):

/**
 * config.h — OZONE TELECOM hub pin map, radio parameters, and credentials.
 *
 * ALL pin numbers below were reverse-engineered from the real schematic
 * (ozone_telecom/ozone_telecom.kicad_sch, peripherals.kicad_sch) by matching
 * each net's global_label coordinate to the ESP32-S3-MINI-1U symbol's pin
 * offsets (symbol placed at (81.28, 96.52), rotation 0 — see the working in
 * the PR/commit message or ask Dash for the derivation script). Where a net
 * could not be pinned down with confidence, it is marked CONFIRM below —
 * you MUST open the schematic and verify (click the net, "Highlight Net",
 * read the ESP32 pin it lands on) before flashing real hardware.
 *
 * Everything here is a #define specifically so Dash can override without
 * touching any .cpp file.
 */
#pragma once

// ============================================================================
// WiFi credentials — EDIT BEFORE FLASHING. Consider moving to NVS / a
// provisioning flow (WiFiManager) once the hub leaves the bench; hardcoding
// is fine for bring-up.
// ============================================================================
#define WIFI_SSID          "OZONE-GCS"
#define WIFI_PASSWORD      "changeme123"
// If AP mode is preferred instead (no local WiFi at the pad), set this and
// see main.cpp's WIFI_MODE_AP branch.
#define WIFI_AP_MODE       0          // 1 = ESP hosts its own AP, 0 = joins WIFI_SSID
#define WIFI_AP_SSID       "OZONE-TELECOM"
#define WIFI_AP_PASSWORD   "rocketry1"

// ============================================================================
// FCD-over-UART link to the STM32 flight computer (USART2 on the FC side,
// PA2/PA3, 115200 8N1 — see docs/telecom-command-protocol.md).
//
// *** CONFIRM THIS IN KICAD BEFORE FLASHING ***
// The schematic nets "TELECOM_TO_OZONE" / "OZONE_TO_TELECOM" trace, by exact
// coordinate match against the ESP32-S3-MINI-1U symbol, to a location
// adjacent to the module's EN (chip-enable/reset) pin cluster — NOT a clean
// GPIO pair like every other net on this board. That's almost certainly
// either (a) a genuine hardware reset/status line rather than the FCD UART
// data pair, or (b) routed through a header on peripherals.kicad_sch that
// this parse didn't fully resolve. Either way: open ozone_telecom.kicad_sch,
// click "TELECOM_TO_OZONE" and "OZONE_TO_TELECOM", and use
// Inspect > Highlight Net to read the real ESP32 GPIO numbers, then fix the
// two #defines below. Placeholders use ESP32-S3's default UART1 pins so the
// firmware at least builds and can be bench-tested with jumper wires.
// ============================================================================
#define PIN_FC_UART_TX     17   // CONFIRM — placeholder (ESP32-S3 UART1 default TX)
#define PIN_FC_UART_RX     18   // CONFIRM — placeholder (ESP32-S3 UART1 default RX)
#define FC_UART_NUM        1    // Serial1
#define FC_UART_BAUD       115200   // matches STM32 USART2 in main.c

// ============================================================================
// E22-900M22S (SX1262) LoRa module — SPI + control lines.
// CONFIRMED from schematic: E22_MISO/MOSI/SCK/NSS/BUSY/NRST/DIO1/RXEN/TXEN
// global labels all land on ESP32 IO0-IO8 as a tight, deliberate group.
// Note: IO0 is an ESP32 boot-strapping pin (must be high/floating at reset
// to boot from flash normally); it also drives E22_RXEN here. In practice
// this is fine — RXEN just needs to settle to its steady state a few ms
// after boot, well before radio use — but do not add an external pulldown
// on RXEN or you risk forcing the module into download mode. Flag for
// Dash to sanity-check on first bring-up.
// ============================================================================
#define PIN_E22_MISO       3
#define PIN_E22_MOSI       5
#define PIN_E22_SCK        4
#define PIN_E22_NSS        6    // SPI chip-select
#define PIN_E22_BUSY       7    // SX1262 BUSY (poll before every SPI txn)
#define PIN_E22_NRST       8    // SX1262 NRESET (active low)
#define PIN_E22_DIO1       2    // SX1262 DIO1 (IRQ: TX/RX done, timeout, etc.)
#define PIN_E22_RXEN       0    // Ebyte E22 RF switch RX-enable (module-level, active high)
#define PIN_E22_TXEN       1    // Ebyte E22 RF switch TX-enable (module-level, active high)
// The E22 module wraps the raw SX1262 with an RF front-end switch driven by
// RXEN/TXEN (Ebyte's own antenna-switch control, separate from the SX1262's
// internal DIO2-as-antswitch option). RadioLib's Module constructor takes an
// optional RXEN/TXEN pair specifically for E22-style boards — wire them in.
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

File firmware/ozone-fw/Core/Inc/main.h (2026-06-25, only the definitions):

#define INT1_H3LIS_Pin GPIO_PIN_0
#define INT1_H3LIS_GPIO_Port GPIOC
#define INT1_LIS3DH_Pin GPIO_PIN_1
#define INT1_LIS3DH_GPIO_Port GPIOC
#define INT2_LIS3DH_Pin GPIO_PIN_2
#define INT2_LIS3DH_GPIO_Port GPIOC
#define SD_CD_Pin GPIO_PIN_3
#define SD_CD_GPIO_Port GPIOC
#define CS_H3LIS_Pin GPIO_PIN_0
#define CS_H3LIS_GPIO_Port GPIOB
#define CS_LIS3DH_Pin GPIO_PIN_1
#define CS_LIS3DH_GPIO_Port GPIOB
#define CS_MS5611_1_Pin GPIO_PIN_2
#define CS_MS5611_1_GPIO_Port GPIOB
#define PYRO1_GATE_Pin GPIO_PIN_10
#define PYRO1_GATE_GPIO_Port GPIOB
#define PYRO2_GATE_Pin GPIO_PIN_11
#define PYRO2_GATE_GPIO_Port GPIOB
#define CS_MS5611_2_Pin GPIO_PIN_12
#define CS_MS5611_2_GPIO_Port GPIOB
#define PYRO1_CONT_LED_Pin GPIO_PIN_13
#define PYRO1_CONT_LED_GPIO_Port GPIOB
#define PYRO2_CONT_LED_Pin GPIO_PIN_14
#define PYRO2_CONT_LED_GPIO_Port GPIOB
#define PYRO_ARM_Pin GPIO_PIN_15
#define PYRO_ARM_GPIO_Port GPIOB
#define PYRO1_CONT_Pin GPIO_PIN_6
#define PYRO1_CONT_GPIO_Port GPIOC
#define PYRO2_CONT_Pin GPIO_PIN_7
#define PYRO2_CONT_GPIO_Port GPIOC
#define LED_HEARTBEAT_Pin GPIO_PIN_6
#define LED_HEARTBEAT_GPIO_Port GPIOB
#define LED_ERROR_Pin GPIO_PIN_7
#define LED_ERROR_GPIO_Port GPIOB
#define PG_BUCKBOOST_Pin GPIO_PIN_8
#define PG_BUCKBOOST_GPIO_Port GPIOB
#define BUZZER_Pin GPIO_PIN_9
#define BUZZER_GPIO_Port GPIOB

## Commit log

2026-04-07 Initial project setup
    [UNSW_Rocketry_Senior_Flight_Computer.kicad_pcb, UNSW_Rocketry_Senior_Flight_Computer.kicad_sch]
2026-04-13 starting work
    [UNSW_Rocketry_Senior_Flight_Computer.kicad_pcb, UNSW_Rocketry_Senior_Flight_Computer.kicad_sch]
2026-04-18 feat: MCU setup
    [UNSW_Rocketry_Senior_Flight_Computer.kicad_sch]
2026-04-18 feat: Power & comms
    [Comms.kicad_sch, Peripherals.kicad_sch, Power.kicad_sch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]
2026-04-19 feat: Comms complete
    [Comms.kicad_sch, Power.kicad_sch, UNSW_Rocketry_Senior_Flight_Computer.kicad_sch]
2026-04-19 feat: Pyro done
    [Power.kicad_sch, Pyros.kicad_sch, UNSW_Rocketry_Senior_Flight_Computer.kicad_sch]
2026-04-19 feat: VBAT Sense
    [Power.kicad_sch, UNSW_Rocketry_Senior_Flight_Computer.kicad_sch]
2026-04-19 feat: finish board (draft)
    [Indication.kicad_sch, UNSW_Rocketry_Senior_Flight_Computer.kicad_sch]
2026-04-19 feat: finish schematic (erc_pass)
    [Peripherals.kicad_sch, Power.kicad_sch, Pyros.kicad_sch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]
2026-04-19 feat: finish schematic (Full)
    [Comms.kicad_sch, Indication.kicad_sch, Peripherals.kicad_sch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]
2026-04-19 feat: BCB Start ( power & pyro done)
    [UNSW_Rocketry_Senior_Flight_Computer.kicad_pcb, UNSW_Rocketry_Senior_Flight_Computer.kicad_sch]
2026-04-22 feat: PCB Designed (Silk screen adjustments)
    [Comms.kicad_sch, Pyros.kicad_sch, UNSW_Rocketry_Senior_Flight_Computer.kicad_sch]
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2026-04-30 feat: add UNSW_ROCKETRY_LIBRARY.pretty footprint library
    Project-specific KiCad footprints used by the schematic and PCB.
2026-04-30 docs: move schematic PDF into docs/ and add Project OZONE
    Fixes broken README links — README on main points to docs/ paths
    but the schematic PDF was sitting at the repo root and the
    Project OZONE document was missing entirely.
2026-05-27 refactor: split project into versioned revision folders
    Move the flight computer project into v0.0/ (frozen known-good) and add
    v1.0/ as a self-contained working copy for the next revision. Each folder
    carries its own footprint library and fp-lib-table (KIPRJMOD-relative), so
    revisions open and fab independently. README documents the new layout.
    v0.0 is also tagged for recovery.
    [Comms.kicad_sch, Indication.kicad_sch, Peripherals.kicad_sch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]
2026-05-27 chore: save working flight computer state as v0.0 baseline
    Final known-good state of the senior FC before splitting into versioned
    revisions (v0.0 frozen, v1.0 for the next revision).
    [UNSW_Rocketry_Senior_Flight_Computer.kicad_pcb, UNSW_Rocketry_Senior_Flight_Computer.kicad_sch]
2026-05-27 v1.0: add Samtec FTSH-105-01-L-DV-K connector to project libraries
    Import the Snapeda FTSH-105-01-*-DV-K part into v1.0 only:
    - footprint into UNSW_ROCKETRY_LIBRARY.pretty
    - symbol into new project UNSW_ROCKETRY_LIBRARY.kicad_sym + sym-lib-table
    - STEP model in UNSW_ROCKETRY_LIBRARY.3dshapes, referenced via KIPRJMOD
    - repoint symbol footprint field to UNSW_ROCKETRY_LIBRARY:, set Value to
    the ordered variant FTSH-105-01-L-DV-K
    v0.0 left untouched.
2026-05-31 v1.0: update schematics and PCB layout
    [Comms.kicad_sch, Power.kicad_sch, Pyros.kicad_sch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]
2026-06-01 Fix: Tims review changes
    [UNSW_Rocketry_Senior_Flight_Computer.kicad_pcb]
2026-06-08 v1.0: update Power/Pyros schematics and PCB; add JUNO_XL and Untitled_2 footprints
    [Power.kicad_sch, Pyros.kicad_sch, UNSW_Rocketry_Senior_Flight_Computer.kicad_pcb]
2026-06-25 Add OZONE flight computer firmware, USB-C console, and ground tools
    STM32CubeIDE project (STM32L452RET6) - builds clean.
    - app/: portable firmware module (regen-safe, sits beside Core/Drivers)
    - sensor drivers: 2x MS5611, H3LIS331DL, LIS3DH on shared SPI1
    - flight state machine with 2-of-3 apogee voting + altitude/velocity lockouts
    - FatFs SD logging, USART2 telemetry, ADC battery/pyro sensing
    - pyro arm/fire/continuity; indication (RGB + buzzer boot signalling)
    - USB-C CDC ground console: preflight / test / post-flight menus
    - tools/: rich+pyserial laptop TUI + pnpm task runner (preflight/monitor/...)
    - docs/ERRATA.md: rev-1.0 hardware notes (no TIM17 -> buzzer on PB9 via TIM6
    so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
    [adc_sense.c, console.c, h3lis331dl.c]
2026-07-22 Add OZONE Telecom radio expansion board (KiCad project + docs)
    New ozone_telecom KiCad project: E22-900M22S LoRa + ESP32-S3-MINI-1U + MAX-M10S GNSS.
    USB-priority PowerPath (LTC4412) with 3x TPS630701/2 buck-boost rails (3V3 + 5V + gated
    servo 5V), INA226 battery sense, TMP1075 temp sensors, servo header, bottom-silk graphic.
    OZONE_RADIO curated symbol/footprint library + custom footprints. Design + RF routing docs.
    E22-900M22S added to shared UNSW_ROCKETRY_LIBRARY (symbol/footprint/3D).
    [ozone_telecom.kicad_pcb, ozone_telecom.kicad_sch, peripherals.kicad_sch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]
2026-07-23 fix(sd): mount fails on good card — BSP gated HAL_SD_Init on unreliable card-detect (ERR-004)
    MX_SDMMC1_SD_Init never calls HAL_SD_Init; the only path to it is via CubeMX
    BSP_SD_Init(), which returned MSD_ERROR_SD_NOT_PRESENT before initialising the
    card whenever BSP_SD_IsDetected() != SD_PRESENT. The rev-1.0 PC3 card-detect
    switch is unreliable (ERR-004) and reads "not inserted" with a good card seated,
    so HAL_SD_Init was never called on any card: f_mount -> FR_DISK_ERR, hsd1.State
    RESET, CardType 0.
    Override the __weak BSP_SD_IsDetected() in the app module (logging.c) to always
    report SD_PRESENT, letting the real SD init/mount be the presence test. Verified
    on hardware: f_mount OK, Stat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
    [console.c, logging.c]
2026-07-23 feat(telecom): pyro trigger auth core (4 fire modes) + protocol design doc [WIP]
    Add pyro_trigger.[ch] - the ground->board fire authorisation state machine for
    the OZONE telecom link, with four selectable fire modes:
    safe - per-fire nonce (prime -> fire token=) (ground tests)
    session - flight "password" set at flight-mode entry (fast emergency; DEFAULT)
    hot - deploy-ready rolling live token, 1-key fire (max replay resistance)
    direct - armed -> fire, no token (fastest, least safe)
    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
2026-07-23 feat(telecom): FC-side FCD protocol over USART2 (telemetry + commands + pyro auth)
    Finish the flight-computer side of the telecom link so it's ready to connect to
    the ESP32 hub / any FCD ground station:
    - link_uart.[ch]: enable USART2 RX (interrupt ring + non-blocking line reader;
    was TX-only) with a regen-safe USART2_IRQHandler + NVIC enable, plus TX.
    - fcd.[ch]: transport-agnostic fcd/1 engine - whoami -> OZONE descriptor,
    TLM key=value stream (rate=tlm_hz), LOG, get/set/do dispatch wired to the app
    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
2026-07-23 fix(pyro): re-pin to fabbed board + analog continuity + correct pyro_vbat (ERR-007)
    The CubeMX .ioc pyro pin map was stale and matched NEITHER v0.0 nor v1.0
    (both schematics agree, verified via kicad-cli netlist). Firmware was reading
    continuity on floating PC6/PC7 and driving swapped gate/arm/CONT-LED pins.
    Corrected via direct OZ_ macro overrides in ozone_hal.h (regen-safe; the GPIOB
    output set is unchanged so MX_GPIO_Init still applies):
    CONT PC6/PC7 -> PA0/PA1
    GATE PB10/PB11 -> PB14/PB15
    ARM PB15 -> PB13
    CONT_LED PB13/14 -> PB10/PB11
    pyro_init() configures PA0/PA1 (+PA4) analog (regen-safe, not in main.c).
    Continuity is an ANALOG divider (R25/R26 = 10k/3.3k) on ADC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
    [console.c, ozone_app.c, ozone_config.h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]
2026-07-23 docs(fcd): copy-pastable AI implementation prompts (ESP32 + STM32)
    Two self-contained prompts a rocketry team can paste into an AI assistant to
    scaffold an FCD/1-compliant board (ESP32 Arduino / STM32 HAL). Each embeds the
    protocol rules, an adaptable descriptor template, transport guidance, and the
    safety-source-of-truth requirement. Intended to be surfaced on the web
    dashboard's docs page so the ground station doubles as a spec hub.
    Claude-Session: https://claude.ai/code/session_01Fpbi9UjkgsgirLqVvi61wZ
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2026-07-23 fix(fcd): stream TLM + LOG over USB CDC too, not just USART2
    The FCD engine only emitted the telemetry stream + LOG lines over USART2 (the
    telecom/ESP32 link). A ground station on the USB-C CDC port (Web Serial) got the
    whoami descriptor — because that's a command reply routed through the console —
    but never the live TLM stream, so it "recognised the board but showed no data".
    emit_tlm() and fcd_log() now also usb_write() when a USB host is connected
    (non-blocking; drops if no reader), so the web dashboard over Web Serial streams.
    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
    [fcd.c]
2026-07-23 feat(fcd): 'do identify' action — blink LED + chirp to locate the board
    Adds an `identify` FCD action (declared in the descriptor, dispatched in fcd.c)
    that flashes the RGB LED cyan + chirps the buzzer x3 via a new app_identify()
    hook, so an operator can confirm which physical board a ground-station link is
    talking to (useful with multiple boards on the bench). Flashed + verified.
    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
    [fcd.c, ozone_app.c]
2026-07-23 fix(usb): reliable CDC TX via ring buffer (was corrupting/dropping TLM)
    usb_write() passed the caller's transient stack buffer straight to
    CDC_Transmit_FS, which holds the pointer and transmits asynchronously — so
    in-flight TLM lines were read from reused stack (garbled, unparseable), and the
    drop-on-busy retry lost most periodic lines (telemetry only appeared sporadically
    around commands). Replace with a 2 KB TX ring: usb_write() COPIES into it;
    usb_cli_pump() drains 256 B chunks to the endpoint only when idle, called every
    super-loop (console + fcd_task) and after each write. Non-blocking, no aliasing,
    no drops until the ring fills. Verified: 8 complete TLM lines/s over USB CDC, none
    cor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
    [fcd.c]
2026-07-23 fix(usb): enlarge CDC TX ring 2KB->8KB so the whoami descriptor isn't truncated
    The ~1.6 KB FCD1 descriptor, written while TLM + the console banner were already
    buffered, could overflow the 2 KB TX ring and get truncated mid-JSON — the ground
    station then failed to parse it ("no whoami"), while small replies (identify ACK)
    fit fine. 8 KB comfortably holds the descriptor plus buffered stream.
    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
2026-07-23 feat(fcd): stream subsystem health so ground-station checks resolve (not "monitoring")
    fcd/1 had no wire representation for check pass/fail, so a ground station could
    only guess — accel/SD showed "monitoring". Now the board streams pg/baro_ok/
    accel_ok/sd_ok in TLM, and each checks[] entry declares a `check` key naming the
    telemetry boolean that means PASS (power->pg, baro->baro_ok, accel->accel_ok,
    sd->sd_ok; pyro stays informational). Adds logging_active() (SD mounted) and
    app_power_good()/app_sd_ok() hooks. vbat channel confirmed correct (PC4/IN13);
    rails reading 0 with no battery connected is expected, not a bug.
    Cla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
    [fcd.c, logging.c, ozone_app.c]
2026-07-23 feat(ground): OZONE web ground station (Next.js) — dashboard, /protocol, /builder
    Next.js 16 + Tailwind v4 FCD/1 ground station in ground/web/. Palantir/Anduril
    mission-control theme (IBM Plex, near-mono + disciplined accent, crisp glass
    panels, drifting-blob backdrop). Self-describing: on connect it whoami's and
    auto-builds the whole UI from the descriptor.
    - Transports: Web Serial (auto-detect OZONE VID/PID, hotplug reconnect), WebSocket
    (ESP32 hub), and an explicit-only simulator. No board -> red hazard disconnect
    screen (never auto-sim).
    - Live TLM graphs, rail bars ("— no batt" when a battery rail reads ~0), checks
    resolved from the board's pg/baro_ok/accel_ok/sd_ok booleans,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
2026-07-23 polish(ground): side-on orientation cam, snippet clip, builder chips/dividers, pyro square row
    - OrientationView: replace the near-top-down camera with a low side-on view
    (pitch 18deg down, yaw 14deg, explicit camera basis) so the board's long axis
    reads horizontally; flat-at-rest still level; scale/triad reduced to avoid clip.
    - Calibration wizard: result snippet <pre> capped at max-h 200px w/ internal
    scroll so a long imu snippet can't overflow and shove the 3D viewer.
    - Builder: palette chips squared off (rounded-[5px], not pills); added labeled
    section dividers ("Live preview" / "FCD1 output") between the builder zones.
    - PyroPanel: 6-channel grid is now one horizontal row of asp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
2026-07-23 docs(fw): onboard firmware reference + commit telecom hub & vanilla dashboard
    - firmware/ozone-fw/FIRMWARE.md: authoritative onboard-code doc — build/flash,
    module map, USB+USART2 FCD links, the 4 pyro fire modes + safety model, the
    corrected rev-1.0 pin map (ERR-007), errata status, pre-flight calibration
    TODO, and current hardware-validation status.
    - firmware/ozone-telecom-fw/: ESP32-S3 telecom hub (PlatformIO) — FCD relay to
    WiFi+BLE+LoRa+GPS. Built, not yet hardware-validated (board not fabbed).
    - firmware/tools/web-dashboard/: original no-build vanilla FCD ground station
    (superseded by the Next.js app in ground/web, kept as a zero-dependency fallback).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
    [config.h, fc_link.cpp, gnss_link.cpp]
2026-07-23 feat(fcd): board->ground flight EVENTS (EVT) — launch/apogee/deploy/pyro/landed
    Add fcd_event() emitting structured `EVT <name> <k=v>` lines over USART2 + USB so
    the ESP/ground react to flight milestones, not just infer from the state field:
    - state transitions -> LAUNCH / BURNOUT / APOGEE / MAIN / LANDED / FAULT
    (with t_ms, agl, vel, max_agl)
    - arm/disarm -> ARMED / DISARMED
    - deploy -> DEPLOY ch=N, then PYRO ch=N result=fired|nofire cont_cleared=0/1
    (cont_cleared = continuity went open after firing = e-match consumed = real fire)
    Auto-deploy now routes through app_fire() so flight + manual fires both announce.
    Descriptor declares the `events` vocabulary. Built clean; NOT yet flashed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
    [fcd.c, ozone_app.c]
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2026-07-23 feat(telecom): dual-SD flight backup — hub mirrors the FC stream to its microSD
    The ESP hub now logs every FC FCD line (TLM/EVT/LOG) to the telecom microSD as
    TCM000.LOG.. on a dedicated FSPI bus (separate from the LoRa HSPI so SD writes
    never stall the relay). Non-blocking RAM buffer, 500 ms poll flush, force-flush
    after every EVT so flight milestones commit promptly; no-card is a graceful
    no-op. Pins SCK/MISO/MOSI/CS = IO36/35/34/33 (schematic-confirmed). Combined
    with the FC's own OZONE*.CSV, the two cards are independent flight backups.
    Not yet hardware-validated (board not fabbed).
    Claude-Session: https://claude.ai/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
    [config.h, main.cpp, sd_log.cpp]
2026-07-23 fix(flight): noise-robust apogee via rolling-average peak-drop (was misfiring on ascent)
    The old apogee detector voted on the sign of an EMA of the raw single-sample
    baro derivative; a host sim showed that under realistic baro noise (+/-5 m) it
    deployed the drogue while still ASCENDING at +21 m/s (the noisy velocity flipped
    negative, and the accel "freefall" vote is true throughout coast either way).
    Replace with the rolling-average design:
    - moving average of altitude (FLIGHT_ALT_AVG_N=10, ~0.5 s @20 Hz)
    - apogee = smoothed altitude fell OZONE_APOGEE_DROP_M (10 m) below its running
    peak for OZONE_APOGEE_DEBOUNCE_N (5) consecutive samples -> a real, sustained
    descent that single-sample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
    [fcd.c, ozone_config.h]
2026-07-26 docs: project handover + save antenna selection & roadmap
    - docs/HANDOVER.md: start-here status doc — repo map, build/flash/run, current
    hardware-validation status, this session's findings & fixes (SD, ERR-007, apogee
    misfire fix, USB streaming, calibrated imu, events, dual-SD), the pre-flight
    to-do, connector/cable ordering guide, and fire-mode safety note. Points to the
    detailed refs (FIRMWARE.md, fcd-protocol.md, antenna doc).
    - docs/antenna-selection-handover.md: previously untracked — now committed so the
    antenna decisions (ANT-916-CW-HW-SMA half-wave omni both ends, U.FL jumpers,
    Yagi TBD) are actually saved.
    - docs/ROADMAP.md: previously untracked project roadmap, now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

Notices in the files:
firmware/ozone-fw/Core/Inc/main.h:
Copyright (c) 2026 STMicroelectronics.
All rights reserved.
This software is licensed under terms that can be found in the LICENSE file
